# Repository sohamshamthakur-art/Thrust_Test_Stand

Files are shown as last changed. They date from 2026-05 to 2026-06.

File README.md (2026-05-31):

# THRUST LOGGER

## Simple OverView
In simple language, here is exactly what this project does: Connects to WiFi (or creates its own standalone hotspot) → initializes the load cell amplifier → tares the scale to zero → reads the thrust data 50 times per second → broadcasts the live data to a web dashboard charts the force in real-time → logs the data to an SD card → stops automatically after a set duration → allows you to download the final CSV directly from your browser.

It stores the recent data in its own memory, so we can still download the logs even if you forget to insert an SD card!

## Technical Overview
From an engineering perspective, this system is a high-speed, headless data acquisition node for static fire testing.
* **Data Acquisition:** It interfaces with an HX711 24-bit ADC to read a calibrated 40 kg load cell at 50 Hz (every 20 milliseconds).
* **Asynchronous Web Server:** It uses ESPAsync WebServer and AsyncTCP to host a single-page HTML/JS application.
* **Real-Time Telemetry:** The firmware utilizes Async WebSocket to broadcast JSON payloads containing timestamp, raw data, kilograms, and Newtons.
* **Fault-Tolerant Storage:** High-speed SPI is used for SD card logging. Concurrently, a ring buffer in RAM constantly stores the last 1200 rows of telemetry. This ensures the most recent test data can be retrieved as a CSV download even if the SD card fails or is missing.

## The Motivation
The core motivation for this project was to establish a solid rocketry team in college. Rather than guessing, this thrust logger allows the team to determine the best propellant composition. By capturing accurate, high-resolution thrust curves, we can safely validate nozzle designs, optimize fuel mixtures, and measure total impulse with professional-grade accuracy.

## PINOUTS

| HX711 | ESP32 |
| :--- | :--- |
| VCC | 5V |
| GND | GND |
| SCK | GPIO 26 |
| D_OUT | GPIO 27 |

| SD CARD MODULE | ESP32 |
| :--- | :--- |
| VCC | 3V3 |
| GND | GND |
| MISO | GPIO 19 |
| MOSI | GPIO 23 |
| SCK | GPIO 18 |
| CS | GPIO 5 |

| LOAD CELL | HX711 |
| :--- | :--- |
| RED | E+ |
| BLACK | E- |
| WHITE | A- |
| GREEN | A+ |

## How It Works & How to Use It

### The Working & Logging Process:
When powered on, the ESP32 initializes the HX711 and takes 5 seconds to let the sensor settle before taring it to zero. It then enters its main loop, polling the sensor at 50 Hz. 

When you hit "Start" on the web dashboard, it creates a new .csv file on the SD card (e.g., test001.csv) and starts recording. For safety during static fires, the system is hardcoded to automatically stop logging after 20 seconds.

### Getting Started (Code Changes):
Before deploying, make sure to update these variables at the top of the sketch:
* **WiFi Mode:** You can set the board to Access Point mode (it creates a network called "ThrustLogger" with password "thrustlab") or Station mode (where it connects to your existing router, like "Soham 1").
* **Calibration Factor:** Update the CALIBRATION_FACTOR (currently set to 68342.55) to match your specific load cell setup.
* **Timing:** If your motor burns longer than 20 seconds, adjust the LOG_DURATION_MS variable.

### Accessing Data:
1. Connect your phone or laptop to the logger's WiFi network.
2. Open your browser and navigate to the dashboard IP address.
3. Click the "Download CSV" button on the web interface to instantly save the flight data to your device.
4. Alternatively, remove the SD card and plug it into your PC to access the historical files.

## Project Gallery

| Hardware & Wiring | Testing & Assembly | CAD & Design |
| :---: | :---: | :---: |
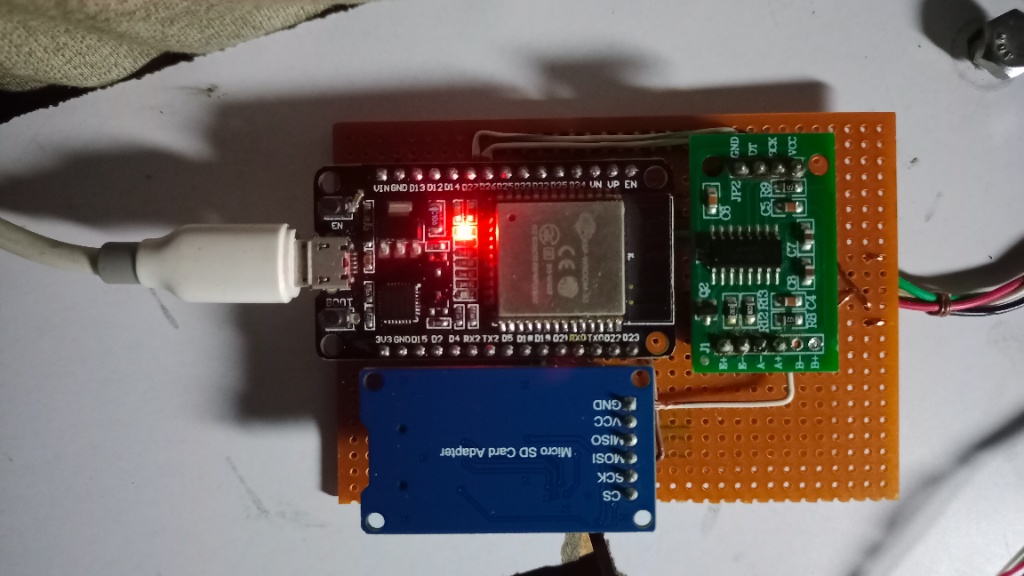
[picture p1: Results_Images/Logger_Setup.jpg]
Logger Setup
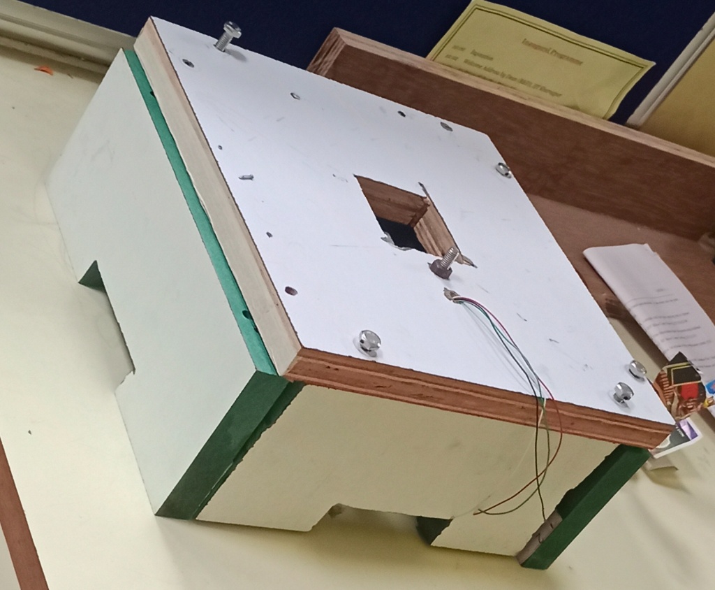
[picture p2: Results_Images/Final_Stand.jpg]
Final Stand
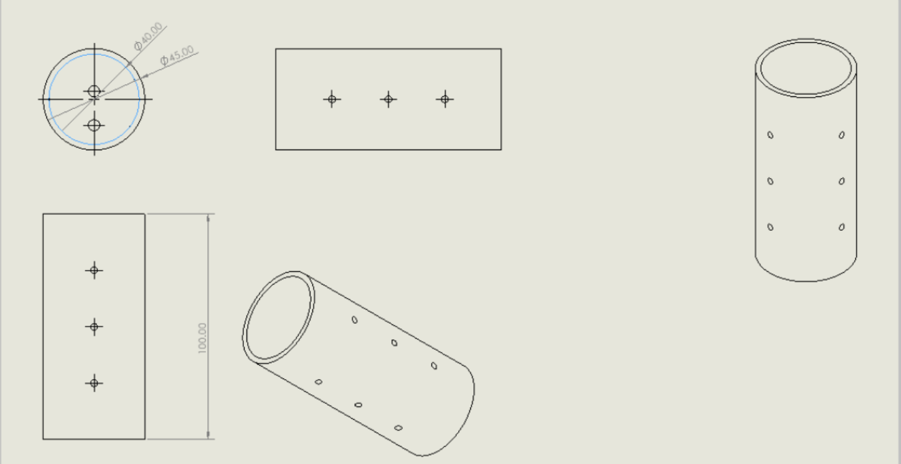
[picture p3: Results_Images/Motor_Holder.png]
Motor Holder
| <br>ESP32 & SD Card Wiring | <br>Constructed Test Stand | <br>SolidWorks Motor Holder |
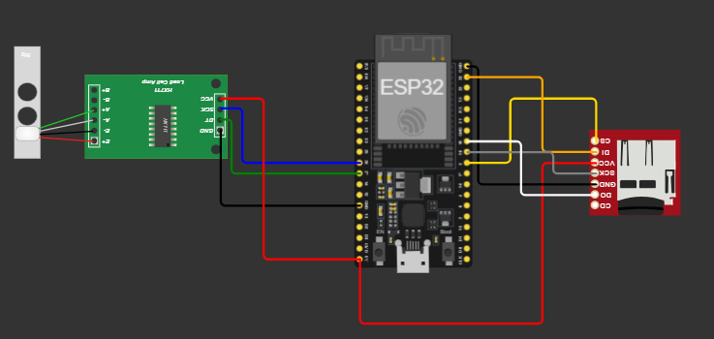
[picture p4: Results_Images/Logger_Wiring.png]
Wiring Diagram
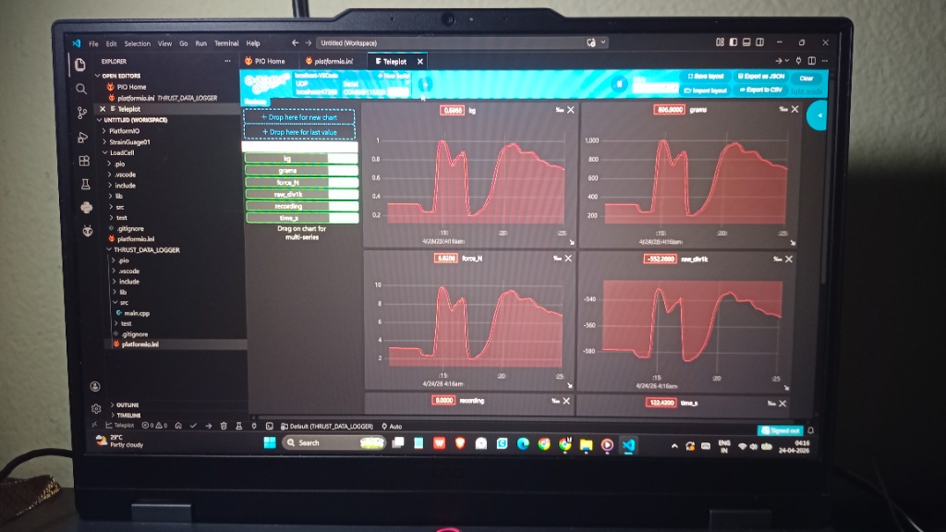
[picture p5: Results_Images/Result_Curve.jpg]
Result Curve
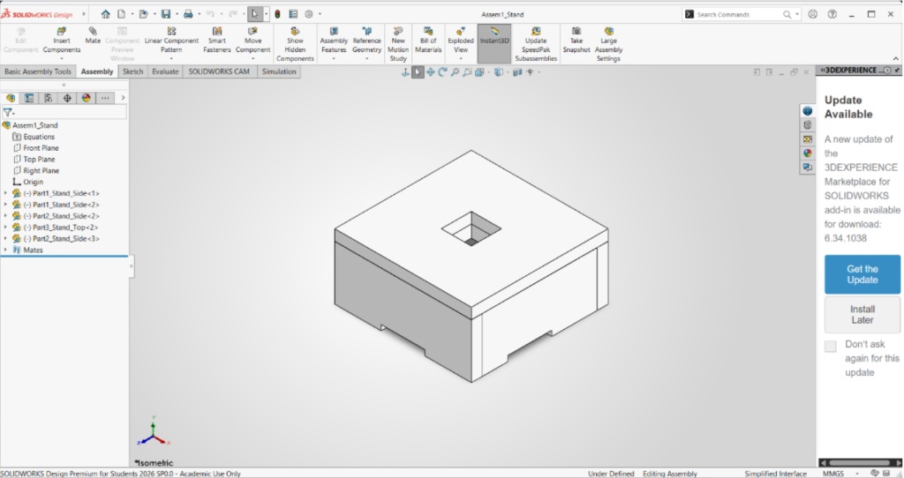
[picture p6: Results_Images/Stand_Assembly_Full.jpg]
Stand Assembly
| <br>Fritzing Circuit Diagram | <br>Live Telemetry Dashboard | <br>SolidWorks Stand Assembly |

## Future Enhancements
While this logger is highly capable, a few additions could expand its utility:
* **Ignition System:** Adding a relay module to trigger the motor's igniter directly from the web dashboard, ensuring a safe distance.
* **Environmental Sensors:** Adding a barometer to record ambient pressure and temperature during the static fire for more precise specific impulse calculations.
* **Over-the-Air (OTA) Updates:** Allowing the firmware to be updated wirelessly at the test site without bringing a USB cable.

## Bye-bye!
Thanks for checking out the project. Fly safe, and happy testing!

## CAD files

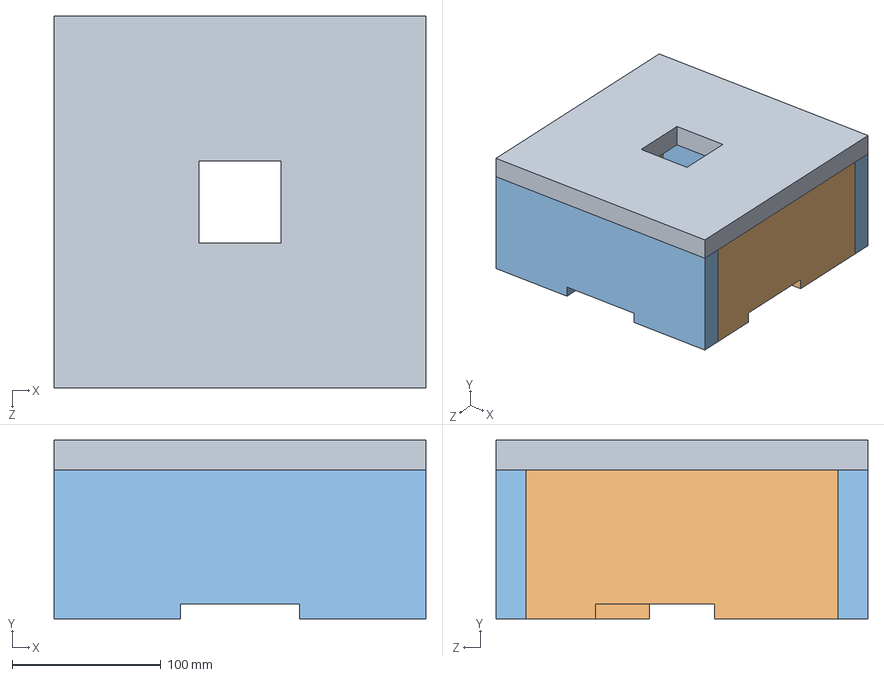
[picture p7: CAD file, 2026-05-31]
CAD&model/Assem1_Stand.SLDASM
250.0 x 120.0 x 250.0 mm
Part1_Stand_Side x 2
Part2_Stand_Side x 2
Part3_Stand_Top

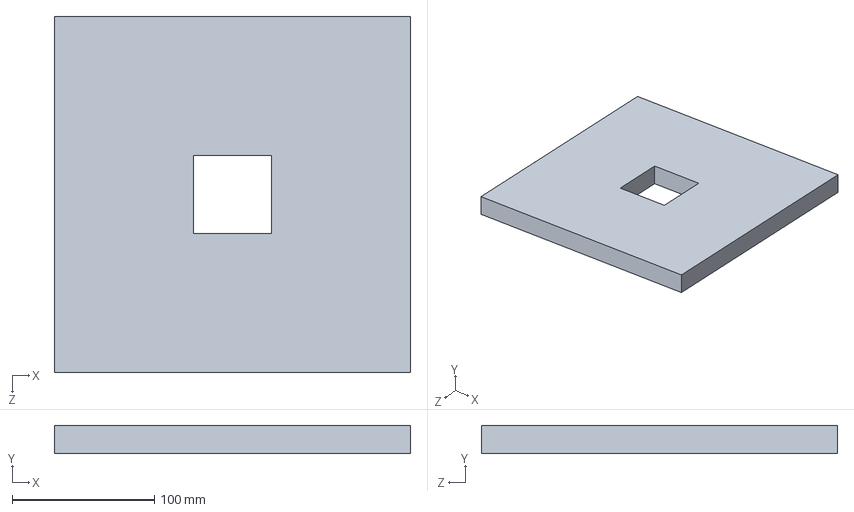
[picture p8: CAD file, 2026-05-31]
CAD&model/Part3_Stand_Top.SLDPRT
250.0 x 20.0 x 250.0 mm

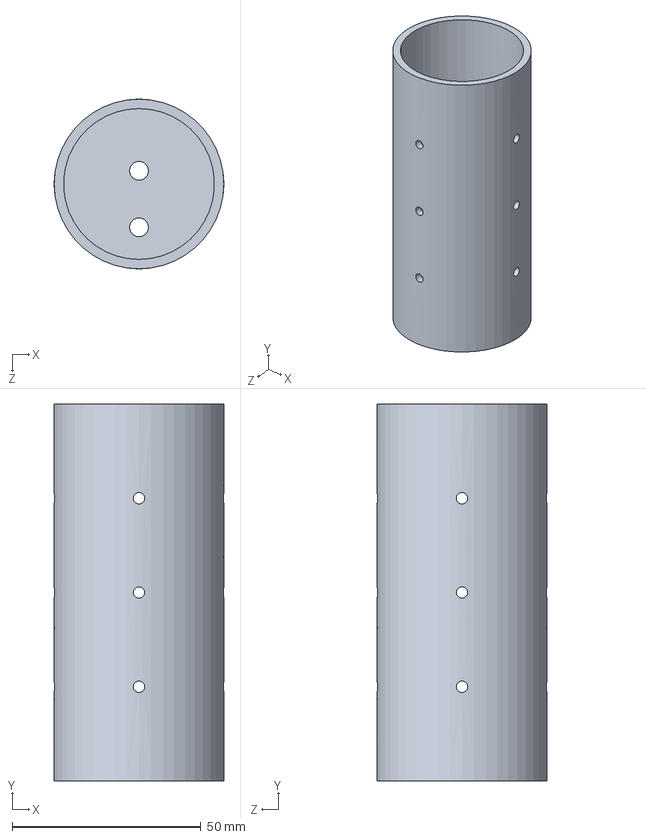
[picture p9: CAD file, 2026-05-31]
CAD&model/Motor_Holder.SLDPRT
45.0 x 100.0 x 45.0 mm

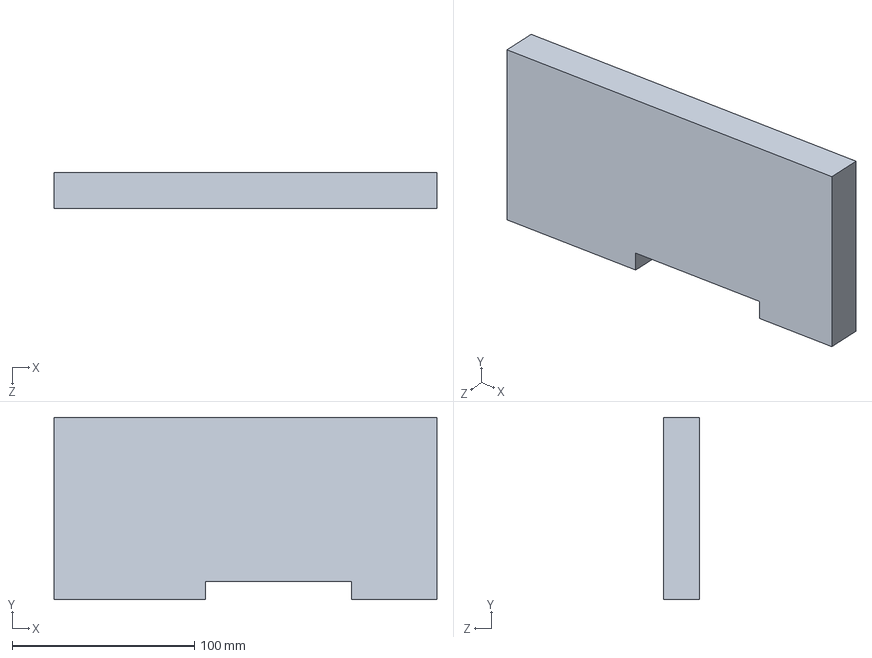
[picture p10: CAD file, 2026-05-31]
CAD&model/Part2_Stand_Side.SLDPRT
210.0 x 100.0 x 20.0 mm

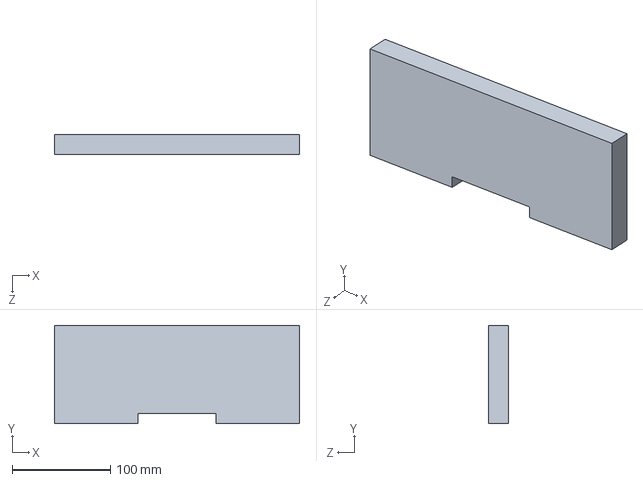
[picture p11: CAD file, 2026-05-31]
CAD&model/Part1_Stand_Side.SLDPRT
250.0 x 100.0 x 20.0 mm

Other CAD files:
CAD&model/Motor_Holder.SLDDRW
CAD&model/Motor_Holder.STL

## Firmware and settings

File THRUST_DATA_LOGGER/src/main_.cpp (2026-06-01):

// =============================================================================
// ESP32 Thrust-Data Logger — WiFi WebSocket Edition
// ---------------------------------------------------------------------------
// Hardware:
//   • ESP32 DevKit
//   • HX711 load-cell amplifier  (DOUT → GPIO 27, SCK → GPIO 26)
//   • Calibrated 40 kg load cell
//   • SD card module over SPI    (CS→5, SCK→18, MISO→19, MOSI→23)
//
// Dependencies (install via PlatformIO / Arduino Library Manager):
//   • bogde/HX711
//   • me-no-dev/ESPAsyncWebServer
//   • me-no-dev/AsyncTCP
//   • ArduinoJson  (bblanchon/ArduinoJson  v7.x)
//
// Access dashboard:
//   AP mode  → connect phone to "ThrustLogger" (pass: thrustlab)
//              then open  http://192.168.4.1
//   STA mode → set WIFI_SSID / WIFI_PASS below, board joins your router,
//              check Serial for IP then open that IP in browser.
// =============================================================================

#include <Arduino.h>
#include <SPI.h>
#include <SD.h>
#include <HX711.h>
#include <WiFi.h>
#include <AsyncTCP.h>
#include <ESPAsyncWebServer.h>
#include <ArduinoJson.h>

// =============================================================================
// WiFi — choose ONE mode
// =============================================================================
// --- AP (Access Point) mode — phone connects directly to ESP32 ---
// #define WIFI_MODE_AP          // comment this out to use STA mode
// static const char* AP_SSID   = "ThrustLogger";
// static const char* AP_PASS   = "thrustlab";   // min 8 chars, or "" for open

// --- STA (Station) mode — ESP32 joins your home/lab router ---
#define WIFI_MODE_STA
static const char* WIFI_SSID = "___";
static const char* WIFI_PASS = "___";

// =============================================================================
// Pin definitions
// =============================================================================
static constexpr uint8_t HX711_DOUT_PIN = 27;
static constexpr uint8_t HX711_SCK_PIN  = 26;

static constexpr uint8_t SD_CS_PIN   = 5;
static constexpr uint8_t SD_SCK_PIN  = 18;
static constexpr uint8_t SD_MISO_PIN = 19;
static constexpr uint8_t SD_MOSI_PIN = 23;

// =============================================================================
// Calibration
// =============================================================================
static constexpr float CALIBRATION_SIGN   =  1.0f;
static constexpr float CALIBRATION_FACTOR =  CALIBRATION_SIGN * 68342.55f;
static constexpr float GRAVITY            =  9.80665f;

// =============================================================================
// Timing
// =============================================================================
static constexpr unsigned long SAMPLE_INTERVAL_MS = 20;    // 50 Hz
static constexpr unsigned long LOG_DURATION_MS    = 20000; // auto-stop 20 s
static constexpr unsigned long FLUSH_INTERVAL_MS  = 500;
static constexpr unsigned long SETTLE_TIME_MS     = 5000;
static constexpr unsigned long WS_BROADCAST_MS    = 20;    // 50 Hz to browser

// =============================================================================
// Globals
// =============================================================================
HX711             scale;
AsyncWebServer    server(80);
AsyncWebSocket    ws("/ws");
File              logFile;

bool     isLogging    = false;
bool     sdReady      = false;
uint16_t fileIndex    = 0;

unsigned long logStartMs    = 0;
unsigned long lastSampleMs  = 0;
unsigned long lastFlushMs   = 0;
unsigned long lastWsBcastMs = 0;

long  tareOffset  = 0;
float scaleFactor = CALIBRATION_FACTOR;

// Ring buffer for CSV download (stores last 10 s @ 100 Hz = 1000 rows)
static constexpr uint16_t CSV_RING_SIZE = 1200;
struct CsvRow { unsigned long ts; long raw; float kg; float grams; float forceN; };
CsvRow csvRing[CSV_RING_SIZE];
uint16_t csvHead = 0;
uint16_t csvCount = 0;

// =============================================================================
// Forward declarations
// =============================================================================
void   doTare();
void   startLogging();
void   stopLogging();
String nextFileName();
void   broadcastSample(unsigned long ts, long raw, float kg, float grams, float forceN);
void   handleWsMessage(AsyncWebSocket* server, AsyncWebSocketClient* client,
                       AwsEventType type, void* arg, uint8_t* data, size_t len);
void   sendCsvDownload(AsyncWebServerRequest* request);
String buildDashboardHTML();

// =============================================================================
// setup()
// =============================================================================
void setup()
{
    Serial.begin(115200);
    delay(800);
    Serial.println(F("\n[BOOT] ESP32 Thrust Logger — WiFi Edition"));

    // --- HX711 ---------------------------------------------------------------
    Serial.println(F("[HX711] Init ..."));
    scale.begin(HX711_DOUT_PIN, HX711_SCK_PIN);

    unsigned long t0 = millis();
    while (!scale.is_ready() && millis() - t0 < 10000) delay(100);
    Serial.println(scale.is_ready() ? F("[HX711] Ready.") : F("[HX711] TIMEOUT!"));

    scale.set_scale(scaleFactor);

    Serial.printf("[HX711] Settling %lu s ...\n", SETTLE_TIME_MS / 1000UL);
    delay(SETTLE_TIME_MS);
    doTare();

    // --- SD card -------------------------------------------------------------
    Serial.println(F("[SD] Init ..."));
    SPI.begin(SD_SCK_PIN, SD_MISO_PIN, SD_MOSI_PIN, SD_CS_PIN);
    sdReady = SD.begin(SD_CS_PIN, SPI);
    Serial.println(sdReady ? F("[SD] OK.") : F("[SD] FAILED (continuing without SD)."));

    if (sdReady) {
        while (fileIndex < 999 && SD.exists(nextFileName().c_str())) fileIndex++;
    }

    // --- WiFi ----------------------------------------------------------------
#ifdef WIFI_MODE_AP
    WiFi.disconnect(true);
    delay(100);
    WiFi.softAP(AP_SSID, AP_PASS[0] ? AP_PASS : nullptr);
    Serial.printf("[WiFi] AP  SSID: %s   IP: %s\n",
                  AP_SSID, WiFi.softAPIP().toString().c_str());
    Serial.printf("[WiFi] Open browser → http://%s\n",
                  WiFi.softAPIP().toString().c_str());
#else
    WiFi.disconnect(true);
    delay(100);
    WiFi.begin(WIFI_SSID, WIFI_PASS);
    Serial.print(F("[WiFi] Connecting"));
    while (WiFi.status() != WL_CONNECTED) { Serial.print('.'); delay(500); }
    Serial.printf("\n[WiFi] Connected.  IP: %s\n", WiFi.localIP().toString().c_str());
    Serial.printf("[WiFi] Open browser → http://%s\n", WiFi.localIP().toString().c_str());
#endif

    // --- WebSocket handler ---------------------------------------------------
    ws.onEvent(handleWsMessage);
    server.addHandler(&ws);

    // --- HTTP routes ---------------------------------------------------------
    // Root — serve dashboard HTML
    server.on("/", HTTP_GET, [](AsyncWebServerRequest* req) {
        req->send(200, "text/html", buildDashboardHTML());
    });

    // CSV download endpoint
    server.on("/download", HTTP_GET, sendCsvDownload);

    // Status endpoint (for health checks)
    server.on("/status", HTTP_GET, [](AsyncWebServerRequest* req) {
        JsonDocument doc;
        doc["logging"]  = isLogging;
        doc["sdReady"]  = sdReady;
        doc["tare"]     = tareOffset;
        doc["scale"]    = scaleFactor;
        String out;
        serializeJson(doc, out);
        req->send(200, "application/json", out);
    });

    server.begin();
    Serial.println(F("[HTTP] Server started."));
    Serial.println(F("\nReady. Open the dashboard URL on your phone or laptop."));
}

// =============================================================================
// loop()
// =============================================================================
void loop()
{
    ws.cleanupClients();

    unsigned long now = millis();

    if (now - lastSampleMs >= SAMPLE_INTERVAL_MS) {
        lastSampleMs = now;

        if (!scale.is_ready()) return;

        long  rawValue = scale.read();
        float kg       = scale.get_units(1);
        float grams    = kg * 1000.0f;
        float forceN   = kg * GRAVITY;

        // Store into ring buffer (always, even if not "logging")
        csvRing[csvHead] = { now, rawValue, kg, grams, forceN };
        csvHead = (csvHead + 1) % CSV_RING_SIZE;
        if (csvCount < CSV_RING_SIZE) csvCount++;

        // Broadcast to WebSocket clients (throttled to 50 Hz)
        if (now - lastWsBcastMs >= WS_BROADCAST_MS) {
            lastWsBcastMs = now;
            broadcastSample(now, rawValue, kg, grams, forceN);
        }

        // Write to SD if logging
        if (isLogging && logFile) {
            logFile.printf("%lu,%ld,%.4f,%.2f,%.4f\n",
                           now, rawValue, kg, grams, forceN);
        }
    }

    // Auto-stop logging after LOG_DURATION_MS
    if (isLogging && (now - logStartMs >= LOG_DURATION_MS)) {
        stopLogging();
    }

    // Flush SD periodically
    if (isLogging && logFile && (now - lastFlushMs >= FLUSH_INTERVAL_MS)) {
        lastFlushMs = now;
        logFile.flush();
    }
}

// =============================================================================
// broadcastSample() — send JSON over WebSocket to all clients
// =============================================================================
void broadcastSample(unsigned long ts, long raw, float kg, float grams, float forceN)
{
    if (ws.count() == 0) return;

    char buf[128];
    snprintf(buf, sizeof(buf),
             "{\"t\":%lu,\"r\":%ld,\"k\":%.4f,\"g\":%.1f,\"n\":%.4f,\"l\":%d}",
             ts, raw, kg, grams, forceN, isLogging ? 1 : 0);
    ws.textAll(buf);
}

// =============================================================================
// handleWsMessage() — receive commands from dashboard
// =============================================================================
void handleWsMessage(AsyncWebSocket* svr, AsyncWebSocketClient* client,
                     AwsEventType type, void* arg, uint8_t* data, size_t len)
{
    if (type != WS_EVT_DATA) return;

    AwsFrameInfo* info = (AwsFrameInfo*)arg;
    if (!info->final || info->index != 0 || info->len != len) return;  // multi-frame guard
    if (info->opcode != WS_TEXT) return;

    String msg = String((char*)data).substring(0, len);

    if (msg == "tare")  { doTare();      client->text("{\"ack\":\"tared\"}"); }
    else if (msg == "start") { startLogging(); client->text("{\"ack\":\"started\"}"); }
    else if (msg == "stop")  { stopLogging();  client->text("{\"ack\":\"stopped\"}"); }
    else if (msg == "ping")  { client->text("{\"ack\":\"pong\"}"); }
}

// =============================================================================
// doTare()
// =============================================================================
void doTare()
{
    Serial.println(F("[TARE] Taring (20 samples)..."));
    scale.tare(20);
    tareOffset = scale.get_offset();
    Serial.printf("[TARE] Offset: %ld | Verify: %.4f kg\n",
                  tareOffset, scale.get_units(5));

    // Notify connected WS clients
    ws.textAll("{\"event\":\"tared\"}");
}

// =============================================================================
// startLogging() / stopLogging()
// =============================================================================
void startLogging()
{
    if (isLogging) return;

    if (sdReady) {
        String fname = nextFileName();
        logFile = SD.open(fname.c_str(), FILE_WRITE);
        if (logFile) {
            logFile.println(F("time_ms,raw,kg,grams,force_N"));
            logFile.flush();
            Serial.printf("[LOG] Started → %s\n", fname.c_str());
            fileIndex++;
        } else {
            Serial.println(F("[LOG] Failed to open file on SD!"));
        }
    } else {
        Serial.println(F("[LOG] No SD — logging to RAM ring buffer only."));
    }

    // Reset ring buffer for a clean recording session
    csvHead  = 0;
    csvCount = 0;

    isLogging  = true;
    logStartMs = millis();
    lastFlushMs = logStartMs;

    ws.textAll("{\"event\":\"started\"}");
}

void stopLogging()
{
    if (logFile) { logFile.flush(); logFile.close(); }
    isLogging = false;
    Serial.println(F("[LOG] Stopped."));
    ws.textAll("{\"event\":\"stopped\"}");
}

// =============================================================================
// nextFileName()
// =============================================================================
String nextFileName()
{
    char buf[20];
    snprintf(buf, sizeof(buf), "/test%03u.csv", fileIndex);
    return String(buf);
}

// =============================================================================
// sendCsvDownload() — serve ring buffer as CSV file download
// =============================================================================
void sendCsvDownload(AsyncWebServerRequest* request)
{
    // Build CSV string from ring buffer
    String csv = "time_ms,raw,kg,grams,force_N\n";
    uint16_t start = (csvCount < CSV_RING_SIZE) ? 0 : csvHead;
    for (uint16_t i = 0; i < csvCount; i++) {
        uint16_t idx = (start + i) % CSV_RING_SIZE;
        char row[80];
        snprintf(row, sizeof(row), "%lu,%ld,%.4f,%.2f,%.4f\n",
                 csvRing[idx].ts, csvRing[idx].raw,
                 csvRing[idx].kg, csvRing[idx].grams, csvRing[idx].forceN);
        csv += row;
    }

    AsyncWebServerResponse* response =
        request->beginResponse(200, "text/csv", csv);
    response->addHeader("Content-Disposition",
                        "attachment; filename=\"thrust_data.csv\"");
    request->send(response);
}

// =============================================================================
// buildDashboardHTML() — returns the full single-page dashboard
// =============================================================================
String buildDashboardHTML()
{
    // The full HTML/CSS/JS dashboard is embedded as a raw string.
    // Kept in a separate file in your repo for readability;
    // here it is inlined for single-file deployment.
    static const char HTML[] PROGMEM = R"HTMLEOF(
<!DOCTYPE html>
<html lang="en">
<head>
<meta charset="UTF-8">
<meta name="viewport" content="width=device-width, initial-scale=1.0, maximum-scale=1.0">
<title>Thrust Logger</title>
<script src="https://cdn.jsdelivr.net/npm/chart.js@4.4.2/dist/chart.umd.min.js"></script>
<style>
  :root {
    --bg: #0a0c10; --panel: #12161e; --border: #1e2530;
    --accent: #00e5ff; --accent2: #ff4b6e; --accent3: #39ff6a;
    --text: #e8eaf0; --muted: #5a6278;
    --font: 'Courier New', monospace;
  }
  * { box-sizing: border-box; margin: 0; padding: 0; }
  body { background: var(--bg); color: var(--text); font-family: var(--font);
         min-height: 100vh; padding: 12px; }
  h1 { font-size: 1.1rem; letter-spacing: 0.2em; color: var(--accent);
       text-transform: uppercase; margin-bottom: 14px; text-align: center; }
  h1 span { color: var(--muted); font-size: 0.7rem; display: block; margin-top: 2px; }

  .status-bar { display: flex; gap: 8px; justify-content: center;
                margin-bottom: 14px; flex-wrap: wrap; }
  .pill { padding: 3px 12px; border-radius: 20px; font-size: 0.7rem;
          letter-spacing: 0.1em; border: 1px solid var(--border); }
  .pill.green  { border-color: var(--accent3); color: var(--accent3); }
  .pill.red    { border-color: var(--accent2); color: var(--accent2); }
  .pill.cyan   { border-color: var(--accent);  color: var(--accent);  }
  .pill.muted  { border-color: var(--muted);   color: var(--muted);  }

  .metrics { display: grid; grid-template-columns: repeat(3,1fr);
             gap: 8px; margin-bottom: 14px; }
  .metric { background: var(--panel); border: 1px solid var(--border);
            border-radius: 8px; padding: 10px 8px; text-align: center; }
  .metric .val { font-size: 1.5rem; font-weight: bold; color: var(--accent); }
  .metric .val.force { color: var(--accent2); }
  .metric .val.gram  { color: var(--accent3); }
  .metric .lbl { font-size: 0.6rem; color: var(--muted);
                 letter-spacing: 0.1em; text-transform: uppercase; margin-top: 3px; }

  .chart-wrap { background: var(--panel); border: 1px solid var(--border);
                border-radius: 8px; padding: 10px; margin-bottom: 14px; }
  .chart-wrap canvas { max-height: 220px; }

  .controls { display: grid; grid-template-columns: 1fr 1fr; gap: 8px;
              margin-bottom: 14px; }
  button { padding: 14px 8px; border-radius: 8px; border: 1px solid;
           font-family: var(--font); font-size: 0.8rem; letter-spacing: 0.1em;
           text-transform: uppercase; cursor: pointer; transition: all 0.15s;
           background: transparent; }
  .btn-tare  { border-color: var(--accent);  color: var(--accent); }
  .btn-start { border-color: var(--accent3); color: var(--accent3); }
  .btn-stop  { border-color: var(--accent2); color: var(--accent2); }
  .btn-dl    { border-color: var(--muted);   color: var(--muted); grid-column: span 2; }
  button:active { opacity: 0.6; transform: scale(0.97); }
  button:disabled { opacity: 0.3; cursor: not-allowed; }

  .log { background: var(--panel); border: 1px solid var(--border);
         border-radius: 8px; padding: 8px; max-height: 110px;
         overflow-y: auto; font-size: 0.68rem; color: var(--muted); }
  .log div { padding: 1px 0; border-bottom: 1px solid var(--border); }
  .log div:last-child { border: none; }
  .log .ev { color: var(--accent); }
  .log .warn { color: var(--accent2); }

  @media (min-width: 600px) {
    body { max-width: 700px; margin: 0 auto; padding: 20px; }
    .metrics { grid-template-columns: repeat(3,1fr); }
    .controls { grid-template-columns: repeat(4,1fr); }
    .btn-dl { grid-column: span 4; }
  }
</style>
</head>
<body>
<h1>⚡ THRUST LOGGER <span id="ip-label"></span></h1>

<div class="status-bar">
  <div class="pill muted" id="pill-ws">WS: CONNECTING</div>
  <div class="pill muted" id="pill-sd">SD: —</div>
  <div class="pill muted" id="pill-rec">● IDLE</div>
  <div class="pill cyan"  id="pill-hz">— Hz</div>
</div>

<div class="metrics">
  <div class="metric"><div class="val" id="val-kg">—</div><div class="lbl">kg</div></div>
  <div class="metric"><div class="val gram" id="val-g">—</div><div class="lbl">grams</div></div>
  <div class="metric"><div class="val force" id="val-n">—</div><div class="lbl">force N</div></div>
</div>

<div class="chart-wrap">
  <canvas id="chart"></canvas>
</div>

<div class="controls">
  <button class="btn-tare"  onclick="sendCmd('tare')">Tare</button>
  <button class="btn-start" id="btn-start" onclick="sendCmd('start')">▶ Start</button>
  <button class="btn-stop"  id="btn-stop"  onclick="sendCmd('stop')" disabled>■ Stop</button>
  <button class="btn-dl"    onclick="downloadCSV()">⬇ Download CSV</button>
</div>

<div class="log" id="log"><div>Initialising...</div></div>

<script>
const MAX_PTS = 300; // last 6 seconds shown at 50 Hz
let ws, reconnTimer;
let lastTs = 0, hz = 0, hzSamples = 0, hzTimer;

// Chart setup
const ctx = document.getElementById('chart').getContext('2d');
const chart = new Chart(ctx, {
  type: 'line',
  data: {
    labels: [],
    datasets: [
      { label: 'kg',      data: [], borderColor: '#00e5ff', borderWidth: 1.5,
        pointRadius: 0, tension: 0.3, yAxisID: 'y' },
      { label: 'Force N', data: [], borderColor: '#ff4b6e', borderWidth: 1.5,
        pointRadius: 0, tension: 0.3, yAxisID: 'y2' }
    ]
  },
  options: {
    animation: false,
    responsive: true,
    maintainAspectRatio: true,
    interaction: { mode: 'index', intersect: false },
    plugins: { legend: { labels: { color: '#5a6278', font: { size: 10 } } } },
    scales: {
      x:  { ticks: { color: '#5a6278', maxTicksLimit: 6, font: { size: 9 } },
             grid: { color: '#1e2530' } },
      y:  { ticks: { color: '#00e5ff', font: { size: 9 } },
             grid: { color: '#1e2530' }, position: 'left', title: { display: true, text: 'kg', color:'#00e5ff', font:{size:9} } },
      y2: { ticks: { color: '#ff4b6e', font: { size: 9 } },
             grid: { drawOnChartArea: false }, position: 'right',
             title: { display: true, text: 'N', color:'#ff4b6e', font:{size:9} } }
    }
  }
});

function addPoint(t, kg, n) {
  const label = (t / 1000).toFixed(2);
  chart.data.labels.push(label);
  chart.data.datasets[0].data.push(kg);
  chart.data.datasets[1].data.push(n);
  if (chart.data.labels.length > MAX_PTS) {
    chart.data.labels.shift();
    chart.data.datasets[0].data.shift();
    chart.data.datasets[1].data.shift();
  }
  chart.update('none');
}

function log(msg, cls) {
  const el = document.getElementById('log');
  const d = document.createElement('div');
  d.textContent = new Date().toISOString().slice(11,19) + ' ' + msg;
  if (cls) d.className = cls;
  el.prepend(d);
  while (el.children.length > 60) el.removeChild(el.lastChild);
}
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
